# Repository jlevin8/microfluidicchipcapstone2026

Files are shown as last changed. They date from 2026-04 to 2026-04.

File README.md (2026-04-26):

# Microfluidic Chip Capstone 2026

Repository containing CFD files, CAD models, Grayscale slicer scripts, and supplemental materials for honors thesis. 

All CFD was performed using OpenFOAM and Paraview. CAD models were developed using AutoDesk Fusion. Grayscale prints were created using ImageJ scripts. 

Author: Josh Levin
William & Mary

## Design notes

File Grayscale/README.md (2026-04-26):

# bamm_slice README adapted from https://github.com/namitn04/bamm_slice/tree/main

This tool turns a 3D model (`.stl`) into a stack of black-and-white PNG images (layers) that the **CELLINK LumenX Gen-3** printer can use. These instructions are for MacOS users.

## 0) Download this project (no Git needed)

1. On the GitHub page, click the green **Code** button → **Download ZIP**.  
2. Double-click the ZIP to unzip it.  
3. You now have a folder (probably called `microfluidicchipcapstone2026-main`). We’ll use that.

> Tip: Put this folder somewhere easy, like your **Desktop**.

---

## 1) Make sure you have Python 3

1. Open **Terminal**  
   - Press `command + space`, type **Terminal**, hit **Enter**.
2. In Terminal, type:
   ```bash
   python3 --version
   ````

* If you see something like `Python 3.10.9`, you’re good.
* If you get an error, ask someone or ChatGPT to help install Python 3 (it’s quick).

---

## 2) Open Terminal **in** the project folder

Do this the easy way:

1. In **Finder**, open the folder (the one you unzipped).
2. In Terminal, type `cd ` (type `c` + `d` + **space** but don’t press Enter yet).
3. Drag the folder from Finder into the Terminal window (this pastes its full path).
4. Press **Enter**.

Your Terminal line should now end with `…/microfluidicchipcapstone2026-main$`

---

## 3) Install the required packages (one copy-paste line)

In Terminal, paste this and press **Enter**:

```bash
python3 -m pip install trimesh pillow numpy shapely scipy networkx rtree
```

* If that doesn’t work, try:

  ```bash
  pip install trimesh pillow numpy shapely scipy networkx rtree
  ```
* If you see a lot of text — that’s normal. Wait until it finishes.

---

## 4) Run the test (just copy and paste)

Navigate to the `slicer` folder in the `grayscale` in the `microfluidicchipcapstone2026-main` folder:

```bash
cd slicer
```

Then run:

```bash
python3 repair_and_slice.py \
  --stl 3X 20x1mm Cylinders.stl \
  --profile lumenx_gen3.json \
  --layer-mm 0.1 \
  --aa 1 \
  --out ./Test_Output
```

**What this does:**

* Uses the included `.stl` model
* Uses the included `lumenx_gen3.json` printer profile
* Slices the model into **0.1 mm** (100 µm) layers
* Saves PNG images into a new folder called **`Test_Output`**

> The output folder (`./Test_Output`) will be created automatically if it doesn’t exist.

---

## 5) Check that it worked

* In Finder, open the **`Test_Output`** folder that was just created.
* You should see a bunch of files named like `layer_0001.png`, `layer_0002.png`, etc.
* Open a few — the white areas are “exposed” (printed), and black is empty.

---

## 6) Use your own STL next time

When you’re ready to slice a different model:

1. Put your `.stl` file into this same folder (or note where it lives).
2. Run the command again, changing the file names:

**If everything is in the same folder (easy):**

```bash
python3 repair_and_slice.py \
  --stl MyModel.stl \
  --profile lumenx_gen3.json \
  --layer-mm 0.1 \
  --aa 1 \
  --out ./MyModel_Output
```

**If your files are elsewhere (full/absolute paths):**

* On a Mac, you can **drag a file from Finder into Terminal** to paste its full path.

```bash
python3 /Users/yourname/Desktop/microfluidiccapstone2026-main/grayscale/slicer/repair_and_slice.py \
  --stl /Users/yourname/Desktop/Models/MyModel.stl \
  --profile /Users/yourname/Desktop/microfluidicchipcapstone2026-main//grayscale/slicer/lumenx_gen3.json \
  --layer-mm 0.1 \
  --aa 1 \
  --out /Users/yourname/Desktop/MyModel_Output
```

---

## What the options mean (plain English)

* `--stl` — your input 3D model (`.stl` file)
* `--profile` — printer settings; use `lumenx_gen3.json` for LumenX Gen-3
* `--layer-mm` — thickness of each layer. Common values:

  * `0.05` (50 µm, finer, more layers)
  * `0.1` (100 µm, default for quick tests)
* `--aa` — “anti-aliasing” (smooth edges). Leave at `1` unless you know you want `2`.
* `--out` — where to save the PNG layers (a folder you name)

**Quick help at any time:**

```bash
python3 repair_and_slice.py -h
```

---

## Common problems (and quick fixes)

**Q: “command not found: python3”**
A: Python 3 isn’t installed or not in PATH. Install Python 3, then try again.

**Q: “No module named …” or “module not found”**
A: Re-run the install step:

```bash
python3 -m pip install trimesh pillow numpy shapely scipy networkx rtree
```

**Q: “No such file or directory: Test.stl / lumenx_gen3.json”**
A: You’re not in the right folder or not referencing the right file path.

* Either `cd` into the correct folder (see Step 2), **or** use full paths by dragging files into Terminal.

**Q: The output folder is empty / not many layers**
A: Your `--layer-mm` might be too big, or your model is extremely thin. Try `--layer-mm 0.05`.

**Q: The model looks off-center in slices**
A: The script auto-centers each layer for you; if something looks odd, check that your model fits the build area (see below).

---

## Safety fit: does your model fit the printer?

The included LumenX Gen-3 profile uses a build area of **68 mm × 38 mm × 100 mm** and a pixel pitch of **0.035 mm** (35 µm).
If your model is larger than that XY area, scale it down in your CAD before slicing.

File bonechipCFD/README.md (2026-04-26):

# bonechipCFD

OpenFOAM simulation case for serpentine microfluidic channel used in honors thesis.

## Purpose
Steady-state laminar flow simulation to characterize:
- pressure drop
- velocity fields
- streamlines
- wall shear behavior

## Key Directories
- 0/ : initial conditions
- 500/ : final solved state
- constant/ : mesh + material properties
- system/ : solver settings

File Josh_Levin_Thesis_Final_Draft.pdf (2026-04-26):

### A Microfluidic Hydrogel-Based Platform for Modeling Transport-Limited Cellular Environments in Diabetes

A thesis presented in Candidacy for Departmental Honors in

Physics

from

The College of William and Mary in Virginia

By

Josh Levin

4/27/2026

Accepted for ________________________________________

_______________________________________ Dr. Indranath Mitra

_______________________________________ Dr. Margaret Saha

_______________________________________ Jonathan Frey

_______________________________________ Dr. Ran Yang

# Abstract

Diabetic microvascular complications are strongly influenced by the transport of glucose

and signaling molecules across vascular barriers, yet many conventional in vitro disease

models expose cells to static bulk concentrations that do not reproduce physiologically

relevant flow and di!usion behavior. To address this limitation, a modular microfluidic

platform was developed to decouple vascular perfusion from tissue exposure using a per-

fused serpentine channel separated from downstream culture chambers by a tunable hy-

drogel transport barrier. The device was fabricated by combining 3D-printed molds with

PDMS soft lithography, and passive hydrostatic pressure was used to generate continuous

flow through the vascular channel. Computational fluid dynamics simulations were used

to characterize pressure, velocity, and wall shear stress profiles, while grayscale-controlled

photopolymerization was used to fabricate hydrogel barriers with adjustable transport

properties. Experimental characterization demonstrated stable hydrostatic perfusion at

approximately 10 µL/min with laminar flow conditions. Hydrogel thickness after equili-

bration depended on grayscale exposure, with mean final thicknesses of 0.768 mm, 0.656

mm, and 0.511 mm for grayscale values of 255, 200, and 150, respectively. Glucose dif-

fusion studies showed that lower grayscale hydrogels produced greater solute transport,

with normalized relative e!ective di!usivity values of 1.00, 1.23, and 1.70 across the same

conditions. These results demonstrate that grayscale photopolymerization can be used

to tune transport behavior within microfluidic systems and that the developed platform

provides a practical framework for constructing more physiologically realistic vascularized

disease models for diabetes research, drug screening, and future endothelialized organ-on-

chip studies.

i

# Contents

Abstract

Acknowledgements

List of Figures

List of Tables

### 1 Introduction

### 2 Theoretical Background

### 3 Methodology

### 4 Results

ii

### 5 Analysis and Discussion

### 6 Conclusion and Future Work

6.3.3 Role of Transient Concentration Spikes vs Di!usion-Limited Exposure 42 6.3.4 Evaluation of Stem Cell Spheroids in Transport-Controlled Environ-

Appendix A: Computational Modeling Files and Repository

# Acknowledgements

I would like to express my sincere gratitude to Dr. Mitra for his guidance, encourage-

ment, and mentorship throughout the development of this thesis. His insight, patience,

and support were invaluable during each stage of this project. I am especially grateful for

the opportunity to conduct research under his supervision and to learn from his multidis-

ciplinary mindset and approach to scientific inquiry and engineering design. His passion

for his work is contagious, and I cannot wait to see the amazing things he will do at this

institution.

I would also like to thank the members of my thesis committee for their time, feedback,

and willingness to evaluate this work. I cannot overstate the immensely positive impact

each one of them has had on my time here. Their expertise and thoughtful consideration

are greatly appreciated.

I am thankful to the faculty, sta!, and students within the Applied Science and

Physics programs at William & Mary for providing an environment that fostered curiosity,

problem-solving, and interdisciplinary learning. I would also like to acknowledge the labo-

ratory members and peers who o!ered technical assistance, discussion, and encouragement

throughout the course of this project.

Finally, I would like to thank my family and friends for their continued support, pa-

tience, and encouragement throughout my undergraduate career. Their confidence in me

helped make the completion of this thesis possible.

Contribution Statement

This thesis was completed alongside Stone Fisher, who led CFD modeling and aided in

CAD design, chip and hydrogel fabrication, and manuscript preparation. Josh Levin led

conceptual development, CAD design, fabrication, experimental testing, data analysis,

ii

and manuscript preparation under faculty supervision.

1

# List of Figures

3.1 Schematic of the microfluidic bone-on-a-chip platform illustrating separa-

tion of convective flow and di!usive transport | 15

3.2 CAD designs of chip molds. (A) Initial linear perfusion design. (B) Inter-

mediate dual-circle design. (C) Final serpentine design | 16

3.3 CAD design of 3D-printed Franz cell di!usion rig. (A) Front view showing

sampling port and top donor compartment. (B) Side view showing assem-

bly; the hydrogel is placed between the top and bottom compartments and

mechanically clamped between them | 20

4.1 Fabrication workflow for the transport-controlled microfluidic platform. (A)

Computer-aided design renderings of the mold geometries used to create the

serpentine vascular channel and downstream chamber structures. (B) Fab-

ricated molds produced by additive manufacturing. (C) Final transparent

PDMS device components following casting and demolding, shown with a

U.S. penny for size reference | 25

4.2 Hydrostatic perfusion setup used for passive flow generation through the

microfluidic device. Side view of the experimental apparatus showing an el-

evated inlet reservoir connected to the device inlet and a downstream outlet

collection vessel, generating flow through a hydrostatic pressure di!erence

due to 1.0 inch height di!erence | 26

4.3 Simulated pressure distribution along the serpentine vascular channel under

steady-state laminar flow conditions (Pa) | 28

4.4 Streamline visualization of fluid flow within the vascular channel (m/s). . . 28

2

4.5 Velocity magnitude distribution within the vascular channel | 29
4.6 Wall shear stress distribution along the vascular channel | 30

4.7 Mean hydrogel thickness over time during immersion in media for grayscale-

defined constructs (255, 200, and 150), demonstrating condition-dependent

dimensional stabilization | 31

4.8 Mean final hydrated thickness after equilibration. Lower grayscale exposure

produced thinner hydrogel barriers. Error bars represent standard deviation. 31

4.9 Early-time view of receiver glucose accumulation highlighting initial di!er-

ences in transport kinetics between grayscale conditions | 32

4.10 Mean receiver-phase glucose concentration over time following donor expo-

sure. Lower grayscale hydrogels exhibited faster and greater glucose transport. 33

4.11 Normalized transport index proportional to e!ective di!usivity after cor-

rection for final hydrogel thickness. Lower grayscale conditions retained

greater apparent intrinsic transport | 34

3

# List of Tables

4.1 Final Mean Thicknesses of Grayscale Hydrogels | 31
4.2 Mean Receiver Concentrations at 10-hour t=Time Point | 32
4.3 E!ective Di!usivity of Grayscale Hydrogels Normalized to 255 | 33

4

# Chapter 1

# Introduction

Diabetes mellitus is a systemic metabolic disorder characterized by chronic hyperglycemia

and widespread vascular and metabolic dysfunction. While its complications in the car-

diovascular, renal, and nervous systems are well characterized, the e!ects of diabetes on

skeletal health remain incompletely understood (Hofbauer et al. 2022;Napoli et al. 2017).

Clinically, both type 1 and type 2 diabetes are associated with increased fracture risk

and impaired bone healing; paradoxically, individuals with type 2 diabetes often present

with normal or elevated bone mineral density despite heightened fragility (Vestergaard

2007;Schwartz 2016). This discrepancy suggests that diabetes impairs bone quality rather

than bone quantity alone. However, the mechanisms underlying diabetes-associated skele-

tal degeneration remain unresolved.

Bone is a metabolically active and highly vascularized tissue that relies on continuous

nutrient supply to sustain osteoblast, osteoclast, and osteocyte function. Glucose serves

as a primary metabolic substrate for bone cells and plays an essential role in osteoblast

di!erentiation and matrix production (Janghorbani et al. 2007;Karner and Long 2017).

In diabetes, systemic glucose dysregulation leads to persistent hyperglycemia, increased

formation of advanced glycation end products (AGEs), oxidative stress, and endothelial

dysfunction, all of which have been implicated in altered bone remodeling (Yamamoto

and Sugimoto 2016;Jain 1987). Yet it remains unclear whether skeletal dysfunction arises

5

primarily from elevated glucose concentration itself, from altered vascular transport, from

AGE-mediated matrix sti!ening, or from a combination of these factors.

A critical but often overlooked variable in experimental models is the mechanism of

glucose delivery. In vivo, glucose is transported through the vascular network and di!uses

across capillary walls before reaching bone cells. This transport process is governed by vas-

cular flow, endothelial permeability, and di!usion gradients (Michel and Curry 1999;Prisby

2017). In contrast, many in vitro studies model hyperglycemia by directly supplement-

ing cell culture media with high glucose concentrations, e!ectively bypassing the vascular

transport step. While experimentally convenient, this approach assumes that concentra-

tion alone determines cellular response and neglects the role of di!usion-mediated trans-

port dynamics. Whether the mode of glucose delivery influences cellular behavior in

diabetic bone disease remains largely unexplored.

Direct investigation of localized glucose di!usion in vivo is technically challenging

due to bone’s dense mineralized matrix and complex vascular architecture (Prisby 2017).

Animal models provide systemic insight but do not easily allow isolation of microvascular

transport variables, and ethical and cost considerations limit their scalability. Traditional

two-dimensional cell culture models lack a vascular interface altogether and therefore fail to

replicate physiologically relevant nutrient transport. Although bone-on-a-chip platforms

have emerged to model bone physiology and drug responses (Y. Zhang et al. 2023;B.

Zhang et al. 2018), few systems are specifically designed to decouple convective flow from

di!usion through a tunable vascular barrier under diabetic conditions. As a result, a

mechanistically focused platform for studying vascular-mediated glucose di!usion in bone

is needed.

In physiological conditions, glucose transport from blood to tissue occurs via convective

flow within vessels followed by di!usion across the capillary endothelium and basement

membrane. Accurate modeling of this process requires spatial separation of flow and

di!usion through a controllable barrier that approximates capillary permeability. Many

existing microfluidic systems do not incorporate a tunable di!usion barrier that mimics

6

capillary basement membrane properties, limiting their ability to investigate transport-

mediated cellular responses. Addressing this gap is essential for determining whether

di!usion dynamics contribute to skeletal dysfunction in diabetes.

The objective of this work is to design and validate a microfluidic bone-on-a-chip plat-

form capable of modeling glucose di!usion through a hydrogel-based barrier into cell com-

partments under physiologically relevant conditions. By focusing specifically on vascular-

mediated glucose transport rather than full organ complexity, this system aims to isolate

a potentially critical but understudied mechanism in diabetic skeletal pathology.

The proposed device incorporates a tunable hydrogel di!usion barrier positioned be-

tween a perfused vascular channel and cell culture compartments. Glucose-rich media flows

through the vascular channel under laminar conditions, while solute transport into the cell

chambers occurs exclusively via di!usion across the hydrogel barrier. This configuration

separates convective transport from cellular exposure, thereby more closely approximat-

ing in vivo nutrient delivery. The hydrogel barrier is engineered to be tunable to relevant

permeability, enabling controlled investigation of concentration gradients and di!usion

kinetics.

This study employs both experimental and computational approaches. A physical

microfluidic device is fabricated and characterized, while computational fluid dynamics

(CFD) simulations are used to model flow profiles, shear stress, and pressure gradients.

CFD-guided design optimization ensures laminar flow and controlled di!usion prior to fab-

rication. The integration of experimental validation and computational modeling enables

systematic analysis of glucose transport mechanisms within a controllable microenviron-

ment.

While this work is motivated by diabetic skeletal dysfunction, the platform is not lim-

ited to studying disease mechanisms alone. By reconstructing capillary-mediated trans-

port in a controlled microfluidic system, this approach enables evaluation of how biological

systems and potential therapies behave under physiologically realistic delivery conditions.

In particular, therapies that perform well under uniform in vitro exposure may exhibit

7

altered e”cacy when subject to di!usion-limited transport, spatial gradients, and temporal

delays. Capturing these e!ects is essential for improving the predictive accuracy of in vitro

models.

Thus, beyond its mechanistic focus, this system establishes a foundation for transport-

informed drug testing and personalized disease modeling, where both biological response

and delivery dynamics can be systematically controlled and evaluated.

8

# Chapter 2

# Theoretical Background

## 2.1 Literature Review

### 2.1.1 Organ-on-a-Chip (OOC) Technology

Current drug discovery and toxicological research are limited by a lack of reliable pre-

dictive models that can accurately assess human physiological responses(Van Norman

2019). Animal models remain a primary source for pharmacokinetic data because they

capture complex in vivo physiology, but they often fail to predict human outcomes due to

species-specific metabolic and physiological di!erences, in addition to raising significant

ethical concerns(Seok, Warren, Cuenca, et al. 2013). Conversely, traditional 2D in vitro

models are simple and low-cost but fail to replicate the dynamic 3D cellular microenvi-

ronment, resulting in cells that lack the morphology, polarity, and behavior observed in

vivo(Edmondson et al. 2014).

Organ-on-a-Chip (OOC) technology has emerged as a bridge between these methods,

combining micro-engineering with 3D cell culture to recapitulate organ-level functions. By

utilizing human cells in dynamic microfluidic environments, these devices provide the me-

chanical and chemical cues (such as fluid flow and shear stress) necessary for more accurate

personalized disease modeling and drug screening. Bone-on-a-chip platforms specifically

allow for the investigation of bone adaptation, repair, and diseases like osteoporosis within

9

a controlled, biomimetic system.

### 2.1.2 The Basement Membrane and Capillary Interface

The basement membrane (BM) is a specialized extracellular matrix structure that un-

derlies endothelial and epithelial tissues, forming a selective barrier between the vascular

lumen and surrounding parenchyma (Yurchenco 2011). Ultrastructurally, it consists of

the lamina lucida, lamina densa, and lamina fibroreticularis. The lamina densa, primarily

composed of type IV collagen and laminins, provides mechanical support and contributes

significantly to molecular filtration properties (Yurchenco 2011).

In bone, nutrient exchange occurs through a highly vascularized network that in-

cludes sinusoidal capillaries within the marrow space (Williamson, Kilo, and Tilton 1993).

Capillary-mediated transport involves convective flow within vessels followed by di!usion

across the endothelial layer and basement membrane before solutes reach interstitial tissue.

Transport is governed by permeability, surface area, and concentration gradients (Bird,

Stewart, and Lightfoot 2002).

In diabetic conditions, microvascular dysfunction and basement membrane thickening

have been documented across multiple tissues (Brownlee 2001). These structural alter-

ations may influence solute flux into tissues; however, most in vitro diabetic bone models

bypass the vascular interface entirely by directly exposing cells to hyperglycemic media.

Consequently, the influence of capillary-mediated di!usion dynamics on skeletal cell be-

havior remains poorly characterized

### 2.1.3 Hydrogels as Biomimetic Sca!olds

Hydrogels are three-dimensional crosslinked polymer networks capable of retaining large

volumes of water, making them structurally and mechanically similar to native ECM

(Peppas et al. 2000). Their high water content supports di!usion of small solutes, while

their mesh size and crosslinking density regulate permeability and mechanical sti!ness.

Photocrosslinkable materials such as polyethylene glycol diacrylate (PEGDA) and

10

gelatin methacryloyl (GelMA) are widely used in microfluidic and tissue-engineered sys-

tems due to their tunable mechanical properties, cytocompatibility, and optical trans-

parency (Zhu and Marchant 2011;Yue et al. 2015). PEG-based hydrogels provide con-

trolled di!usivity with minimal protein adsorption, whereas GelMA incorporates bioactive

motifs that promote cell adhesion.

In this work, a hydrogel layer functions as an artificial basement membrane positioned

between a perfused vascular channel and cell compartments. By tuning polymer concen-

tration and crosslinking density, the hydrogel permeability can be adjusted to approximate

physiological capillary transport while maintaining mechanical stability. Unlike rigid mem-

branes, hydrogel barriers more closely resemble the compliant and hydrated structure of

native capillary interfaces.

## 2.2 Governing Physics

### 2.2.1 Mass Transport and Di!usion Kinetics

Solute transport across the hydrogel barrier is governed primarily by passive di!usion. For

time-dependent systems, concentration profiles are described by Fick’s Second Law:

ωC
ωt = D→²C

where C is solute concentration, D is the e!ective di!usion coe”cient within the hy-

drogel, and t represents time.

Within polymeric networks, e!ective di!usion coe”cients are reduced relative to free

solution and depend on mesh size, tortuosity, and solute–polymer interactions (Bird, Stew-

art, and Lightfoot 2002). Small molecules such as glucose (↑ 180Da) typically experience

modest hindrance, whereas larger macromolecules may exhibit restricted transport.

Transport selectivity in hydrogels arises through two primary factors: size exclusion

determined by the relationship between solute hydrodynamic radius and mesh size, and

interaction-based filtering, including electrostatic and hydrophobic interactions that alter

e!ective di!usivity independent of size (Bird, Stewart, and Lightfoot 2002;Amsden 1998).

11

When modeling small di!usion cells, lateral di!usion at the membrane edges (“edge

e!ects”) can artificially elevate apparent steady-state flux if not properly constrained,

particularly when the e!ective di!usion area exceeds the exposed cross-sectional region

(Bird, Stewart, and Lightfoot 2002). Device geometry must therefore be incorporated into

computational modeling.

### 2.2.2 Computational Fluid Dynamics and Laminar Flow

Microfluidic systems typically operate at low Reynolds numbers (Re <1–100), where vis-

cous forces dominate inertial forces and flow remains laminar (Whitesides 2006). Under

laminar conditions, velocity profiles are predictable and mixing occurs primarily by di!u-

sion rather than turbulence.

CFD simulations are employed to validate laminar flow conditions within the vascular

channel, predict wall shear stress experienced by endothelial cells, model velocity and

pressure gradients, and optimize channel geometry to ensure uniform concentration along

the barrier.

For perfused systems with su”ciently high flow rates relative to di!usion flux, the

donor channel may be approximated as an infinite source, maintaining a near-constant

concentration at the hydrogel boundary (infinite dose assumption).

### 2.2.3 Glucose Transport and Utilization Modeling

Glucose transport within biological systems involves both passive di!usion through ex-

tracellular environments and active cellular uptake. In many cell types, glucose uptake

is mediated by facilitative transporters such as GLUT proteins and can be described us-

ing Michaelis–Menten kinetics, where uptake rate depends on local glucose concentration.

Glucose uptake in bone cells is mediated primarily by facilitative glucose transporters such

as GLUT1 and, under certain conditions, GLUT4 (Brownlee 2001;Williamson, Kilo, and

Tilton 1993).

In systems where transport and consumption are coupled, spatial concentration profiles

12

may be influenced not only by di!usion but also by cellular metabolic demand, potentially

leading to localized depletion gradients. Modeling such behavior typically requires cou-

pling di!usion equations with reaction terms representing cellular uptake.

In the present work, transport analysis focuses on di!usion-driven delivery across the

hydrogel barrier, and cellular consumption is not explicitly modeled. This simplification

allows isolation of transport dynamics as a primary variable. However, incorporation

of coupled di!usion–consumption models represents an important extension for future

studies, particularly in the context of evaluating metabolically active systems such as

stem cell spheroids.

## 2.3 Theoretical Assumptions

To enable tractable analysis and computational modeling, several simplifying assumptions

are applied to the system. These assumptions are selected to preserve the dominant

physical behavior while allowing analytical and numerical treatment of transport processes.

The hydrogel barrier is not assumed to be globally homogeneous. In the present

design, spatial variations in crosslinking density may be introduced through grayscale-

controlled photopolymerization to approximate structural heterogeneity observed in native

basement membranes. However, for modeling purposes, the hydrogel is treated as locally

homogeneous, such that within su”ciently small regions the e!ective di!usion coe”cient

may be considered constant. This allows application of Fickian di!usion within each local

domain while permitting spatial variation in transport properties at larger scales.

The e!ective di!usion coe”cient D is therefore treated as a spatially varying parameter,

D=D(x,y,z), reflecting heterogeneity in mesh size and crosslinking density. In simplified

models or initial approximations, an average or e!ective di!usion coe”cient may be used

to represent bulk transport behavior.

Solute transport across the hydrogel is assumed to occur primarily through passive

di!usion, with negligible convective flow within the gel matrix. This assumption is justified

by the low permeability and small pore size of the hydrogel, which suppresses bulk fluid

13

motion.

At the interface between the vascular channel and the hydrogel, solute concentration

is assumed to be continuous, with no preferential partitioning or interfacial resistance.

Additionally, due to continuous perfusion of the vascular channel, concentration at the

hydrogel boundary is approximated as constant over time, consistent with an infinite

source condition.

The hydrogel–cell chamber interface is assumed to allow unrestricted di!usion into

the receptor compartment, without additional transport barriers. Cellular uptake and

consumption of solutes are not included in the present transport model, allowing isolation

of di!usion-driven behavior.

Finally, the system is assumed to operate under steady-state or quasi-steady-state

conditions for flow, with transient e!ects considered only in di!usion analysis. These

assumptions collectively enable focused investigation of transport dynamics while main-

taining relevance to the physical behavior of the system.

14

# Chapter 3

# Methodology

## 3.1 System Overview

The development of the bone-on-a-chip microfluidic platform follows an iterative engineer-

ing design framework consisting of three sequential phases: (1) fabrication optimization,

(2) transport and fluidic validation, and (3) biological characterization. The system is

engineered to isolate and model capillary-mediated passive di!usion of soluble factors into

a compartmentalized tissue microenvironment. While diabetic conditions serve as a pri-

mary application, the platform is designed more broadly as a transport-controlled testbed

for evaluating biological response under physiologically relevant delivery constraints.

As shown in Figure 3.1, the device consists of a serpentine vascular channel (top

layer) connected to inlet and outlet ports, positioned above multiple cell culture chambers

(bottom layer). A hydrogel di!usion barrier is embedded at the interface between the

channel and each chamber, permitting passive transport of soluble factors while preventing

direct convective flow into the cellular compartment. This architecture enables controlled

delivery of nutrients and signaling molecules, allowing cells to experience spatially and

temporally varying concentrations that more closely mimic in vivo capillary-mediated

transport.

Unlike conventional static 2D cultures, this system spatially separates convective flow

from cellular compartments using a hydrogel-based di!usion barrier. By incorporating con-

15

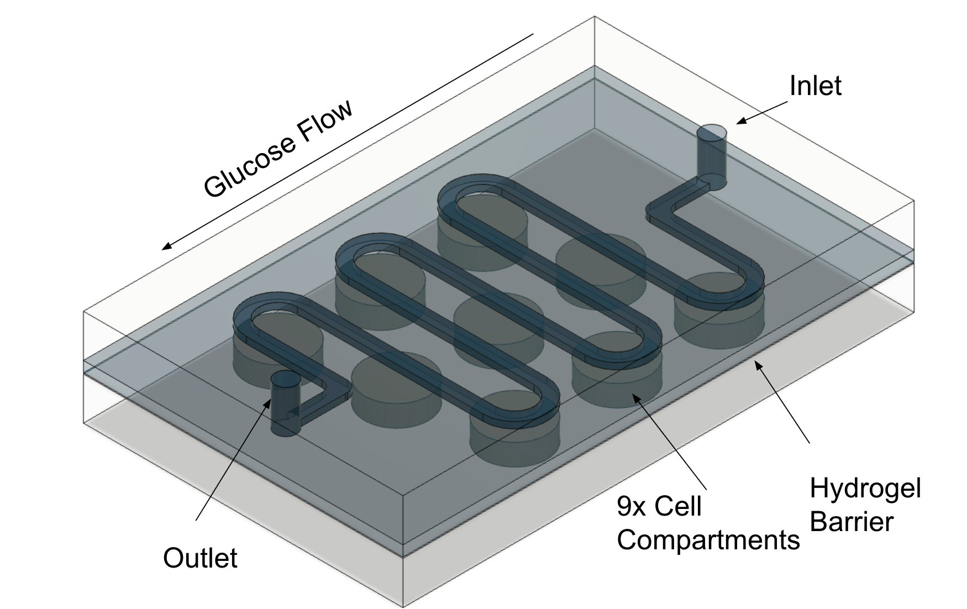
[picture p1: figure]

Figure 3.1: Schematic of the microfluidic bone-on-a-chip platform illustrating separation of convective flow and di!usive transport.

trolled laminar perfusion and tunable solute permeability, the platform enables mechanis-

tic interrogation of vascular-mediated transport under diabetic conditions. This approach

bridges the gap between reductionist in vitro systems and complex in vivo physiology

while maintaining experimental controllability.

## 3.2 Device Design and Fabrication

### 3.2.1 CAD and Microfluidic Architecture

The final microfluidic platform developed in this study was preceded by several itera-

tive design stages aimed at balancing physiological relevance, manufacturability, residence

time, and experimental throughput. Because the primary objective of the system was to

model vascular transport to downstream tissue chambers, the geometry of the perfused

channel required progressive refinement to improve exposure dynamics while maintain-

ing straightforward fabrication through soft lithography. The major design stages are

summarized in Figure 3.2.

The first design iteration employed a simple linear perfusion channel positioned above

two downstream cell compartments (Figure 3.2-A). In this concept, fluid entered through a

single inlet, traveled through a straight vascular channel, and exited through a downstream

outlet. Two circular culture chambers were aligned beneath the channel to receive di!usive

transport through the hydrogel barrier separating the vascular and tissue regions.

16

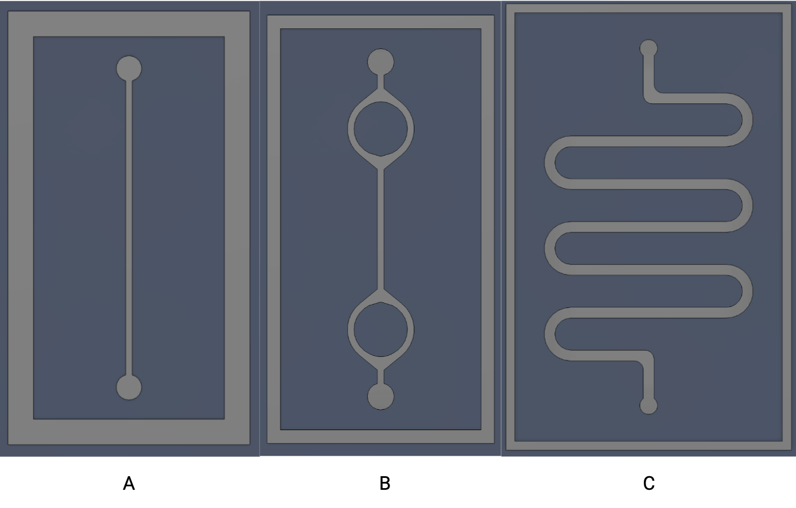
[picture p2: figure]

Figure 3.2: CAD designs of chip molds. (A) Initial linear perfusion design. (B) Intermediate dual-circle design. (C) Final serpentine design.

This design was selected as an initial prototype because of its simplicity and low

fabrication risk. Straight channels are easy to model computationally, easy to mold using

additive manufacturing, and less susceptible to flow irregularities or trapped air bubbles

during early testing. Additionally, the minimal geometry allowed rapid evaluation of

bonding methods, leakage behavior, hydrogel placement, and general perfusion feasibility

before committing to more complex layouts.

However, the straight-channel design exhibited several conceptual limitations. Most

notably, the short flow path produced limited fluid residence time above the downstream

compartments, reducing the duration of local nutrient and solute exposure. The design

also poorly represented the tortuous nature of physiological microvasculature and o!ered

only two tissue compartments, restricting throughput and comparative studies. Because

exposure conditions were likely dominated by rapid axial transport rather than prolonged

exchange, a more developed geometry was pursued.

To increase path length while preserving a compact footprint, a second design iteration

was developed in which the vascular channel looped around two circular regions before

continuing downstream (Figure 3.2-B). In this architecture, the channel traced circular

paths around each compartment, increasing total channel length relative to the straight

design while maintaining two primary culture sites.

The rationale for this geometry was to enhance fluid residence time and create longer

vascular contact regions surrounding each chamber. By increasing the time perfusate

17

spent adjacent to the tissue compartments, the design was expected to improve di!usive

transport opportunities across the hydrogel barrier.

Despite these advantages, several limitations remained. The system still contained

only two culture chambers, limiting experimental throughput. Channel length increased

only modestly relative to later designs, and the circular loops did not fully utilize the

available chip footprint. Additionally, the compartment arrangement was less modular

and did not provide multiple spatial positions for comparing upstream versus downstream

exposure e!ects. As a result, a higher-density architecture was pursued.

The final design iteration employed a serpentine vascular channel spanning the full

device footprint, coupled with an expanded downstream chamber array (Figure 3.2-C).

This geometry substantially increased channel length while maintaining a compact pla-

nar footprint and introduced repeated turns resembling the tortuous routing commonly

observed in vascular networks.

The serpentine channel was selected for several reasons. First, the extended flow path

increased hydraulic residence time, allowing solutes more time to di!use across the hy-

drogel barrier before outlet removal. Second, the repeated curvature generated localized

variations in velocity and wall shear stress that more closely resemble nonuniform physio-

logical flow conditions than a straight channel. Third, the design used chip area e”ciently,

enabling integration of multiple tissue compartments without increasing device size.

The chamber array was expanded from earlier two-chamber designs to a total of nine

compartments to improve throughput and enable spatial comparisons. Six chambers were

positioned adjacent to curved serpentine segments, while three were located near relatively

straight sections of channel. This arrangement was intentionally selected to investigate

whether local residence time or geometric flow di!erences influenced downstream transport

behavior. Curved segments were expected to exhibit slightly longer local interaction times

and altered flow distributions compared with straightaways, potentially a!ecting solute

delivery to neighboring chambers.

Although the serpentine design introduced greater fabrication complexity than the

18

earlier linear geometries, the increased channel length, higher compartment density, and

improved physiological resemblance justified the transition. The final architecture pro-

vided the most versatile platform for studying transport-controlled cellular exposure while

retaining compatibility with PDMS molding and hydrostatic pressure-driven perfusion.

Overall, the CAD development process demonstrates that the final chip geometry was

not selected arbitrarily, but emerged through iterative engineering refinement in response

to the competing requirements of transport performance, manufacturability, and experi-

mental utility.

The microfluidic device is designed using Computer-Aided Design (CAD) software

(Autodesk Fusion 360), incorporating established organ-on-a-chip architectural principles

(Waheed et al. 2016). The platform consists of a sandwich design, with a serpentine per-

fused vascular channel (donor compartment) making up the top PDMS slab, a hydrogel

barrier in the middle, and nine independent cell culture chambers (receptor compart-

ments), arranged symmetrically with three chambers per side and three in the middle.

The vascular channel connects inlet and outlet ports to enable continuous perfusion of

glucose-containing media under controlled flow rates. Each cell chamber interfaces with the

vascular channel via a dedicated aperture engineered to house a hydrogel di!usion barrier.

This barrier prevents convective mixing while permitting passive solute transport.

Channel geometry is designed to maintain laminar flow (Re <100) and uniform solute

concentration along the hydrogel interface. The cylindrical layout reduces concentration

gradients between the upstream and downstream compartments.

3.2.2 3D Printing and Material Selection

Device fabrication is performed using Digital Light Processing (DLP) 3D printing due to

its high resolution (10–30 µm), rapid prototyping capability, and reproducibility (Waheed

et al. 2016)(Huh et al. 2010). Candidate materials include biocompatible photocurable

resins and PDMS validated for microfluidic applications (Waheed et al. 2016).

Molding with Sylgard 184 PDMS (10:1 base:curing agent ratio) is used for fabrication.

19

PDMS remains widely used in microfluidics due to optical transparency, gas permeability,

and ease of plasma bonding (Bhatia and Ingber 2014). Dimensional fidelity and channel

integrity are verified by microcaliper measurement.

### 3.2.3 Hydrogel Barrier Fabrication and Integration

A semi-permeable hydrogel membrane functions as a biomimetic surrogate of the capil-

lary basement membrane. Photocrosslinkable hydrogels such as PEGDA and GelMA are

selected due to their tunable crosslink density, biocompatibility, and well-characterized

di!usion properties.

Hydrogel precursor solution containing photoinitiator (LAP) is introduced into the

DLP print vat. Controlled UV or visible-light exposure induces crosslinking, forming a

stable membrane that is then placed between the PDMS slabs.

Hydrogel thickness, polymer concentration, and crosslinking time are systematically

varied to modulate e!ective di!usion coe”cients. Membrane formation is validated visu-

ally and through leakage testing prior to transport experiments.

## 3.3 Transport Validation and Data Acquisition

### 3.3.1 Computational Fluid Dynamics (CFD)

CFD simulations are conducted using OpenFOAM CFD to evaluate hydrodynamic be-

havior and solute transport. The Navier–Stokes equations are solved under steady-state

laminar flow conditions (Amsden 1998).

Medium properties are modeled as water at 37°C, with dynamic viscosity (µ) = 7.75

× 10 kg/(m·s) and density (ω) = 1000 kg/m³. Simulations are performed to confirm

Reynolds number within laminar regime, quantify wall shear stress on endothelial surfaces

and evaluate velocity uniformity along the hydrogel interface.

20

### 3.3.2 Di!usion and Permeability Assays

Quantitative characterization of hydrogel transport behavior required the development

of a practical di!usion testing method compatible with the mechanically soft grayscale-

printed hydrogel samples used in this study. Because these hydrogels were intended to

function as transport barriers within the microfluidic platform, an experimental system

was needed that could isolate the material between donor and receiver compartments while

maintaining structural integrity during multi-hour testing.

Initial Franz Cell–Inspired Di!usion Chamber Design

The initial approach employed custom 3D-printed di!usion cells (see Figure 3.3) inspired

by traditional Franz di!usion chambers. These devices were fabricated from polyethylene

terephthalate glycol (PETG) and consisted of donor and receiver reservoirs designed to

sandwich the hydrogel sample between two rigid printed halves. Mechanical compression

was applied using binder clips to seal the assembly and prevent leakage.

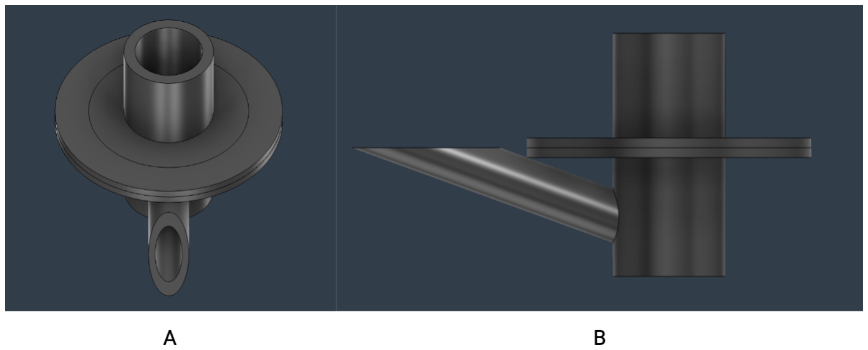
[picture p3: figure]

Figure 3.3: CAD design of 3D-printed Franz cell di!usion rig. (A) Front view showing sampling port and top donor compartment. (B) Side view showing assembly; the hydrogel is placed between the top and bottom compartments and mechanically clamped between them.

This method o!ered several theoretical advantages. First, it provided clear physi-

cal separation between donor and receiver chambers, enabling one-dimensional transport

through the hydrogel barrier. Second, the clamped design was low-cost, reusable, and

rapidly fabricated using standard additive manufacturing methods. Third, the chamber

geometry allowed straightforward filling and sampling of both compartments.

However, repeated testing revealed a critical limitation: the grayscale-defined hydrogels

21

lacked su”cient mechanical robustness to withstand sustained compressive loading at the

sealing interface. Even moderate binder clip pressure frequently caused tearing, cracking,

edge deformation, or rupture of the hydrated gels during assembly. Because seal integrity

depended directly on compression force, reducing clamp pressure often led to leakage, while

increasing pressure damaged the hydrogel. This tradeo! made the Franz cell approach

unreliable for fragile hydrogel formulations.

Following these failures, several additional mechanically clamped testing concepts were

considered, including using syringes as donor and receptor chambers. While these designs

could potentially lower local stress concentrations, they retained the same fundamental

challenge: accurate di!usion measurements required leak-free compartment separation,

while the hydrogels could not reliably tolerate compressive sealing loads. Given project

time constraints and limited material availability, continued iteration on compression-

based fixtures was deprioritized.

Final Six-Well Plate Drop Di!usion Method

A simplified static di!usion assay was therefore adopted using standard six-well culture

plates. In this final configuration, individual hydrogels were placed in wells containing a

defined volume of media as the receiver. A concentrated donor droplet containing glucose

solution was then deposited directly on the upper hydrogel surface.

In this arrangement, glucose transport occurred from the donor droplet through the

hydrogel thickness into the surrounding receiver media below. Receiver-phase glucose con-

centration was measured at scheduled time points using a glucometer to compare relative

transport behavior across grayscale conditions.

The six-well plate method was selected because it eliminated the need for mechanical

compression, substantially reducing hydrogel damage and sample loss. It also enabled

parallel testing of multiple conditions and replicates using widely available laboratory ma-

terials. Sample loading, retrieval, and handling were significantly faster than with custom

clamped fixtures, improving experimental throughput during late-stage thesis testing.

22

The final method was intentionally selected as a comparative transport assay rather

than a perfect classical di!usion cell analog. Its major benefits included no compres-

sive stress on fragile hydrogels, rapid parallel testing of multiple grayscale conditions,

minimal custom hardware requirements, and reduced leakage risk relative to clamped fix-

tures. However, its limitations included less strictly defined one-dimensional transport

geometry, possible donor droplet spreading variability, potential evaporative e!ects dur-

ing long-duration tests, and greater sensitivity to hydrogel placement consistency. This

made it more appropriate for relative di!usivity comparisons than absolute permeability

extraction.

Despite these limitations, the method was su”cient to resolve reproducible grayscale-

dependent transport trends and therefore served to determine whether grayscale-controlled

photopolymerization could be used to tune hydrogel barrier transport properties.

For each condition, equilibrated hydrogels were transferred into six-well plates con-

taining receiver media of known volume. A glucose donor droplet of fixed volume and

concentration was applied to the hydrogel surface using the pipette guide fixture. Re-

ceiver media glucose concentration was then measured at predetermined intervals over 48

hours. Triplicate samples were tested for each grayscale condition (255, 200, and 150),

and resulting concentration profiles were used to estimate relative e!ective di!usivity after

correction for measured hydrogel thickness.

### 3.3.3 Hydrostatic Pressure-Driven Flow

Continuous flow within the microfluidic device is achieved using a hydrostatic pressure-

driven setup. Fluid reservoirs connected to the inlet and outlet ports are positioned at

di!erent vertical heights to establish a gravitational pressure gradient across the device.

The inlet reservoir consists of a vertically mounted syringe or fluid column containing

glucose- or solute-enriched media. The outlet tubing is directed to a waste reservoir

positioned at a lower elevation. The resulting height di!erence between the fluid levels

generates a pressure di!erential that drives flow through the vascular channel.

23

To ensure reproducibility across experiments, all devices are operated under identical

height di!erences, and tubing lengths and diameters are kept consistent to maintain uni-

form hydraulic resistance. Prior to each experiment, all channels and tubing are primed

with media to eliminate air bubbles, which can disrupt flow stability.

Flow rates are estimated by collecting e#uent over a fixed time interval and calculating

the volumetric flow rate. These measurements are used to verify that experimental flow

conditions fall within the laminar regime predicted by CFD simulations.

To minimize temporal variation in flow rate due to depletion of the inlet reservoir,

relatively large fluid volumes are used such that the change in hydrostatic head over the

course of the experiment remains small. This approach enables sustained, low-Reynolds-

number perfusion suitable for long-duration transport and cell culture studies.

24

# Chapter 4

# Results

## 4.1 Device Fabrication and Dimensional Validation

The microfluidic platform was successfully fabricated using a mold-based soft lithography

workflow designed to produce a vascular serpentine channel adjacent to a larger down-

stream cell chamber separated by a hydrogel interface region. The device geometry was

first designed in CAD software and exported as a stereolithography (STL) model for

additive manufacturing of the mold. Following mold fabrication, polydimethylsiloxane

(PDMS) was cast, cured, and removed from the mold to generate the final microfluidic

layer. Inlet and outlet ports were created with syringe tips to permit fluidic connection to

external reservoirs, and the device was subsequently bonded to a flat substrate to complete

the enclosed channel architecture. Representative images of the design, printed mold, and

cured PDMS chips are shown in Figure 4.1.

Measured device dimensions were compared to the nominal geometry defined in the

CAD model to assess fabrication accuracy. The microchannel had sub-millimeter dimen-

sions, with an average height of 0.468 ± 0.022 mm and width of 0.881 ± 0.105 mm, consis-

tent with the design intent. The total channel length was measured to be approximately

21.01 mm, aligning with the expected serpentine geometry used to increase residence time.

The cell compartment dimensions (3.038 ± 0.030 mm width and 1.354 ± 0.008 mm height)

were also consistent across samples and matched the intended expansion of the di!usion

25

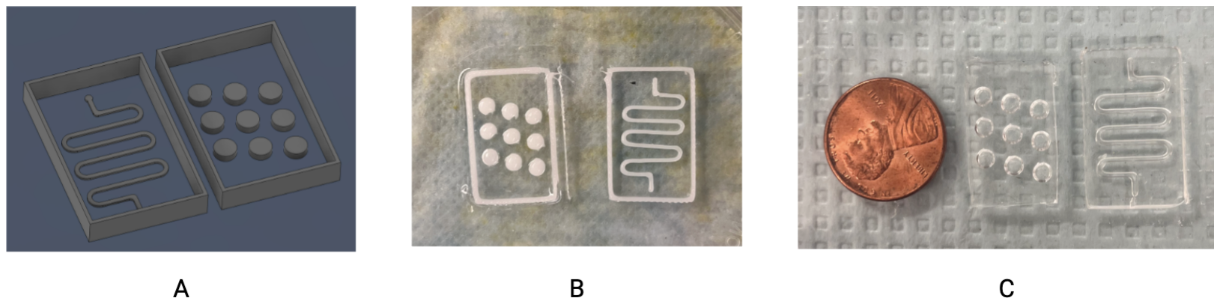
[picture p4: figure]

Figure 4.1: Fabrication workflow for the transport-controlled microfluidic platform. (A) Computer-aided design renderings of the mold geometries used to create the serpentine vascular channel and downstream chamber structures. (B) Fabricated molds produced by additive manufacturing. (C) Final transparent PDMS device components following casting and demolding, shown with a U.S. penny for size reference.

region relative to the microchannel. Minor deviations from the nominal design are at-

tributed to fabrication limitations and measurement uncertainty at small scales, but these

di!erences are not expected to impact flow or transport behavior significantly. Overall,

the fabricated device dimensions demonstrate acceptable agreement with the design speci-

fications and support the validity of subsequent experimental and computational analyses.

## 4.2 Flow Characterization and Validation of the Vascular

## Channel

Hydrodynamic performance of the vascular channel was evaluated to determine whether

the fabricated device could sustain stable perfusion under physiologically relevant mi-

crofluidic conditions. Flow through the serpentine channel was driven passively using a

hydrostatic pressure gradient established by a height di!erence between inlet and outlet

reservoirs (See Figure 4.2). This approach eliminated the need for external pumps while

enabling steady low-flow operation over extended time periods.

The measured average flow rate under standard operating conditions was approxi-

mately 10 µL/min based on outlet volume collection. Given the measured channel cross-

sectional dimensions (0.881 mm width × 0.468 mm height), this corresponds to an average

linear velocity of approximately 0.40 mm/s within the channel. This velocity lies within

26

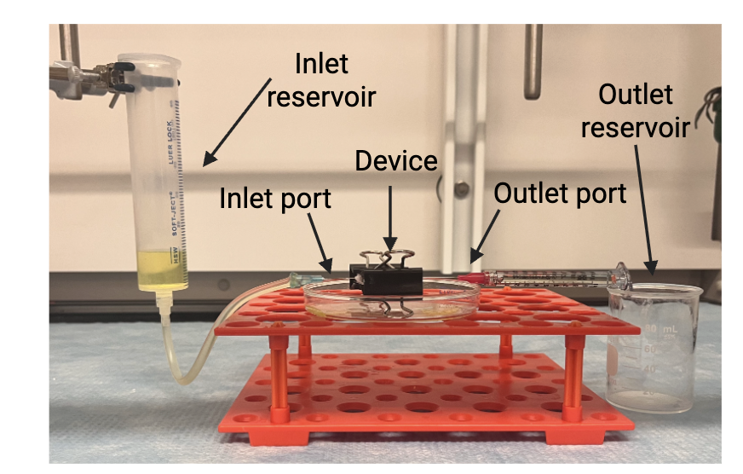
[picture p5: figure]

Figure 4.2: Hydrostatic perfusion setup used for passive flow generation through the microfluidic device. Side view of the experimental apparatus showing an elevated inlet reservoir connected to the device inlet and a downstream outlet collection vessel, generating flow through a hydrostatic pressure di!erence due to 1.0 inch height di!erence.

the lower range reported for physiological capillary microcirculation, where resting capil-

lary blood velocities on the order of 0.3–1.8 mm/s have been observed, and is therefore

consistent with low-shear microvascular transport environments (Hudetz 1997). As a re-

sult, the selected operating condition was considered suitable for mimicking transport

conditions relevant to nutrient delivery in vivo.

The Reynolds number was estimated using measured geometry and water-like fluid

properties:

Re = εUD
µ

where U is the mean velocity, and D is the hydraulic diameter of the rectangular

channel. Under the measured flow condition, the Reynolds number remained well below

unity, confirming strongly laminar flow dominated by viscous forces. This behavior is

27

expected in microfluidic systems and is advantageous because it produces predictable

transport conditions without turbulence or flow instabilities.

Computational fluid dynamics simulations further supported the experimental obser-

vations. Velocity contours demonstrated a relatively uniform axial flow profile through the

straight channel segments, with localized increases in velocity near channel bends due to

curvature-induced redistribution of streamlines. Pressure decreased monotonically along

the length of the serpentine path, indicating consistent hydraulic resistance throughout

the device. Streamline plots showed smooth trajectories without recirculation zones or

stagnation regions.

The serpentine geometry increased the e!ective channel length to approximately 80

mm while maintaining a compact device footprint. This extended path length provided two

functional advantages: increased hydraulic resistance, allowing physiologically relevant low

flow rates to be achieved using modest hydrostatic pressure, and increased residence time,

permitting prolonged interaction between the flowing media and the hydrogel transport

interface.

At the measured average velocity of 0.40 mm/s, the estimated fluid residence time

through the vascular channel was approximately:

t = L

U = 80mm
0.40mm/s ↑ 200s.

or roughly 3.3 minutes. This residence time is su”cient to support sustained solute

exchange along the hydrogel interface during perfusion.

Overall, both experimental measurements and computational modeling indicate that

the device successfully supports stable, low-Reynolds-number perfusion in a physiologi-

cally relevant flow regime. These results validate the serpentine vascular channel as an

appropriate upstream transport module for subsequent di!usion-controlled studies.

Pressure distribution along the serpentine channel confirms a stable pressure-driven

flow regime. As shown in Figure 4.3, pressure decreases monotonically from inlet to

outlet, with no abrupt discontinuities or localized regions of stagnation. This smooth

gradient indicates that flow is governed by viscous forces and that the system operates

28

under steady-state conditions. The absence of pressure irregularities ensures a consistent

driving force for fluid motion, which is critical for maintaining uniform solute delivery

along the hydrogel interface.

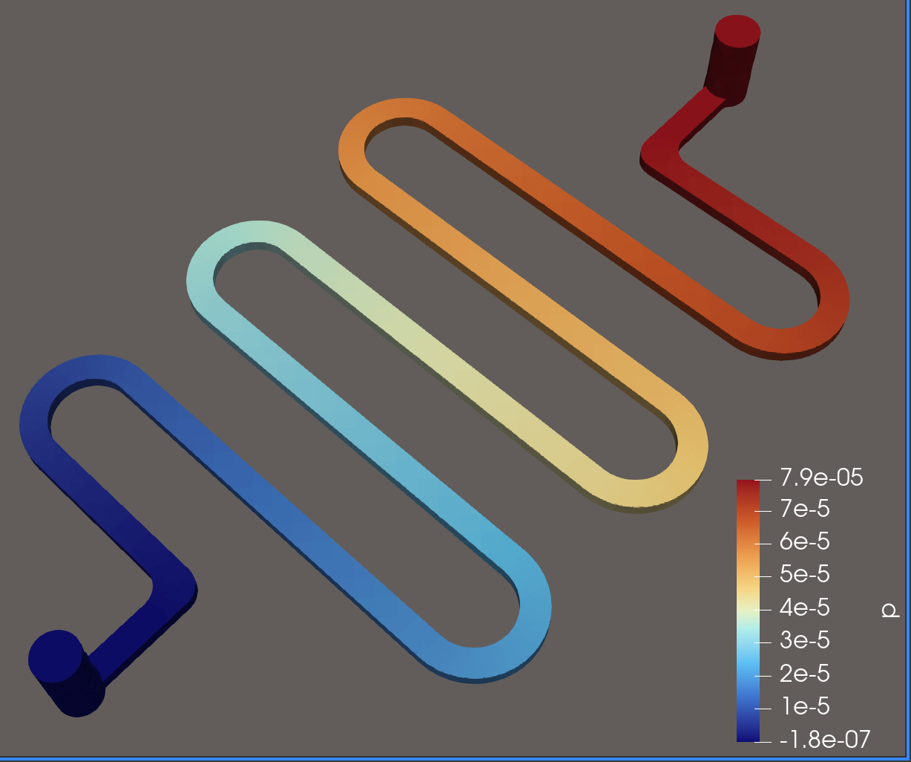
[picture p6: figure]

Figure 4.3: Simulated pressure distribution along the serpentine vascular channel under steady-state laminar flow conditions (Pa).

Flow structure within the channel further supports laminar behavior. Streamline vi-

sualization (Figure 4.4) demonstrates smooth, continuous flow paths that closely follow

the channel geometry, including through curved segments. No recirculation zones or vor-

tices are observed, indicating that inertial e!ects are negligible and that mixing within the

channel occurs primarily through di!usion rather than turbulence. This is consistent with

the low Reynolds number regime typical of microfluidic systems and ensures predictable

transport of solutes to the di!usion barrier.

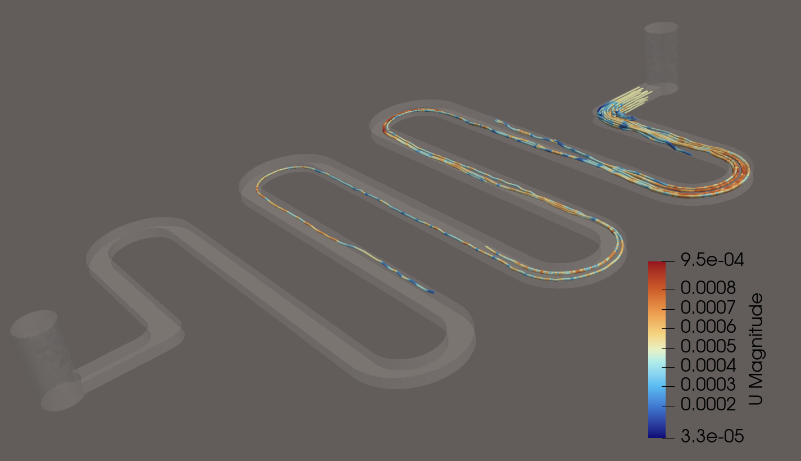
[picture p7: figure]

Figure 4.4: Streamline visualization of fluid flow within the vascular channel (m/s).

29

Velocity field analysis provides additional confirmation of stable flow conditions. As

shown in Figure 4.5, velocity profiles exhibit characteristic laminar behavior, with maxi-

mum velocities at the channel center and reduced velocities near the walls due to viscous

drag. Importantly, velocity remains relatively uniform along the length of the channel,

despite the serpentine geometry. This spatial consistency supports the assumption of a

near-constant solute concentration at the hydrogel boundary, justifying treatment of the

vascular channel as an e!ectively well-mixed donor compartment in subsequent transport

analysis.

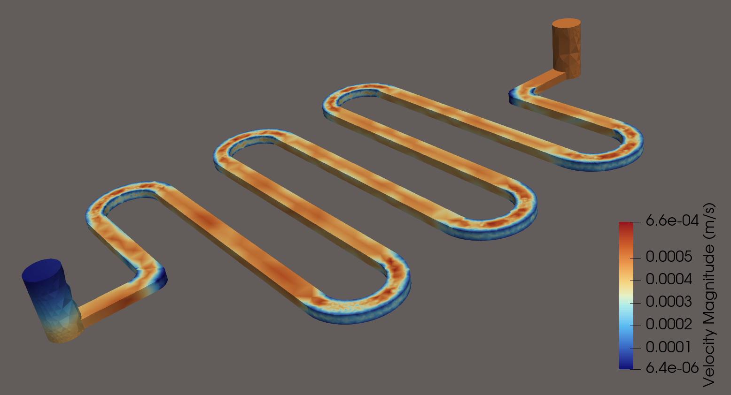
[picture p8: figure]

Figure 4.5: Velocity magnitude distribution within the vascular channel.

Wall shear stress was evaluated to characterize mechanical conditions at the channel

interface. As shown in Figure 4.6, shear stress is elevated at channel bends, where direc-

tional changes in flow induce higher velocity gradients, and reduced in straight sections.

Overall shear levels remain low and within ranges typical of microfluidic perfusion systems.

While endothelial cells are not incorporated in the current study, these values suggest that

the system is compatible with future integration of vascular cell layers without inducing

excessive mechanical stress.

Taken together, these results demonstrate that the vascular channel provides stable,

laminar, and spatially consistent flow conditions suitable for controlled solute delivery. The

absence of recirculation, uniform velocity distribution, and predictable pressure gradient

support the use of this system as a well-defined upstream boundary for di!usion-driven

transport across the hydrogel barrier.

30

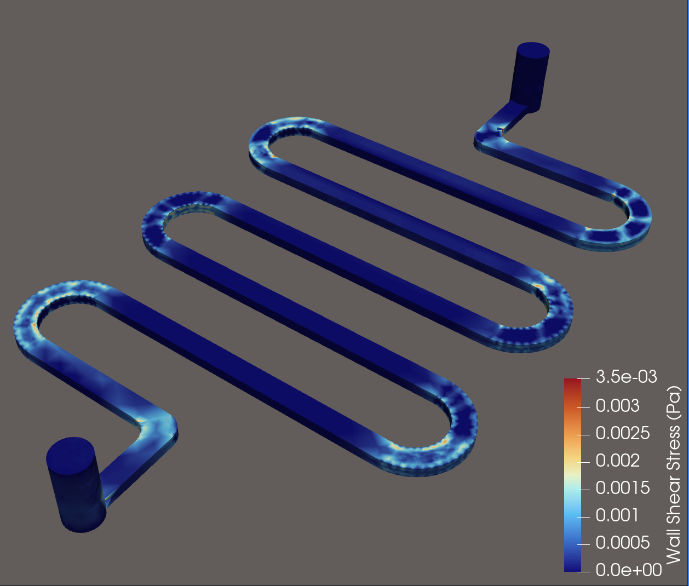
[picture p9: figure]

Figure 4.6: Wall shear stress distribution along the vascular channel.

## 4.3 Hydrogel Characterization and Di!usion Tuning

The hydrogel interface serves as the central transport-regulating component of the mi-

crofluidic platform. In the present system, grayscale-controlled photopolymerization was

used to generate hydrogels with di!ering e!ective crosslink densities, allowing transport

behavior to be tuned through fabrication parameters rather than changes in bulk chem-

istry. Three representative grayscale conditions (255, 200, and 150) were evaluated to

determine how grayscale exposure influenced hydrogel dimensional stability and glucose

transport.

### 4.3.1 Hydrogel Dimensional Equilibration in Media

Prior to di!usion testing, hydrogels were conditioned in culture media to assess dimen-

sional stability under hydrated operating conditions. Thickness and mass were measured

over time as the materials equilibrated. Across all conditions, hydrogels exhibited time-

dependent changes in geometry during the initial exposure period, followed by stabilization

at later time points. Representative thickness trends are shown in Figure 4.7.

Final equilibrated thicknesses di!ered systematically across grayscale conditions. The

highest grayscale condition (255) retained the greatest final thickness, while progressively

lower grayscale values resulted in thinner final structures. Mean final thicknesses are

31

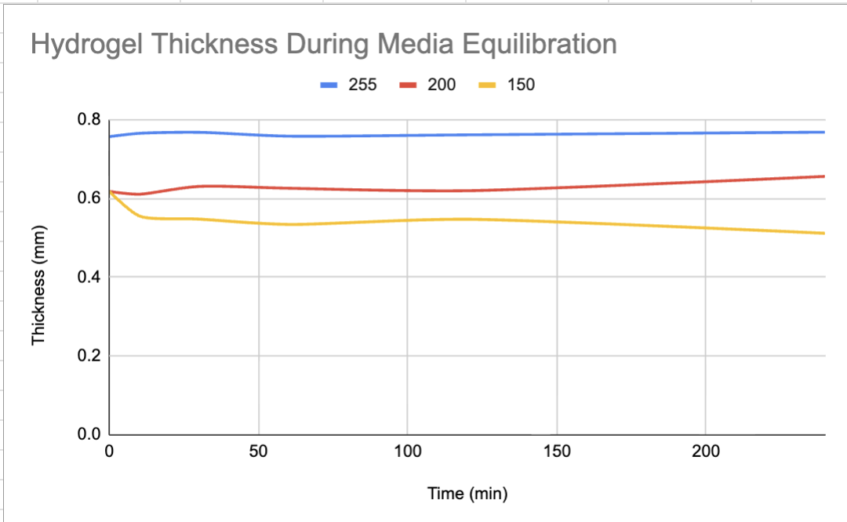
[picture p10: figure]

Figure 4.7: Mean hydrogel thickness over time during immersion in media for grayscale-defined constructs (255, 200, and 150), demonstrating condition-dependent dimensional stabilization.

Table 4.1: Final Mean Thicknesses of Grayscale Hydrogels

255 | 200 | 150
0.768 mm | 0.656 mm | 0.511 mm

shown in Table 4.1 and Figure 4.8.

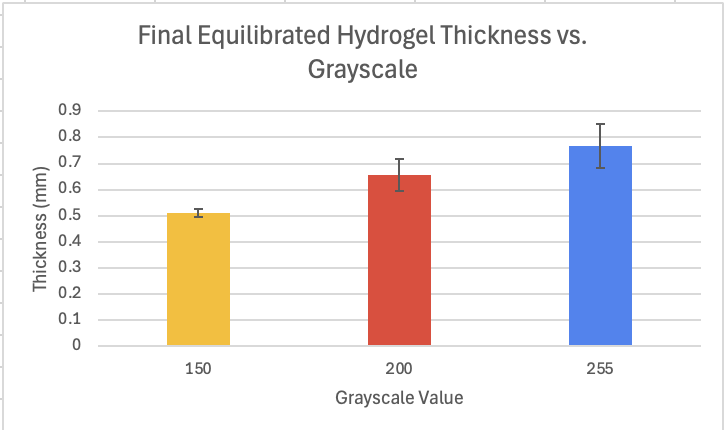
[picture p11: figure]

Figure 4.8: Mean final hydrated thickness after equilibration. Lower grayscale exposure produced thinner hydrogel barriers. Error bars represent standard deviation.

The observed decrease in final thickness with reduced grayscale exposure is consis-

tent with lower photopolymerization dose and reduced network crosslink density. Less

crosslinked hydrogels are expected to exhibit decreased structural rigidity and greater di-

mensional contraction or partial material loss during equilibration. In contrast, higher

grayscale constructs retained greater structural integrity in media.

Mass measurements exhibited greater variability than thickness data, likely due to

surface liquid retention and handling e!ects during weighing. As a result, thickness was

32

Table 4.2: Mean Receiver Concentrations at 10-hour t=Time Point

255 | 200 | 150
151 mg/dL | 181 mg/dL | 246 mg/dL

used as the primary geometric parameter for subsequent transport analysis.

### 4.3.2 Glucose Transport Across Grayscale-Defined Hydrogels

Glucose transport experiments were conducted by exposing one side of each hydrogel to

glucose-containing media and monitoring concentration increases in the receiver phase

over time. Mean glucose concentration profiles are shown in Figure 4.9.

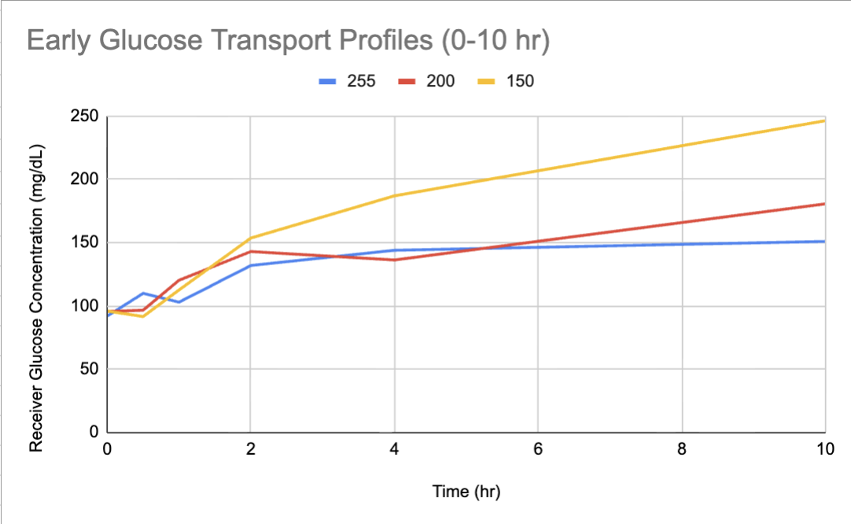
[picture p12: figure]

Figure 4.9: Early-time view of receiver glucose accumulation highlighting initial di!erences in transport kinetics between grayscale conditions.

All conditions demonstrated increasing receiver-phase glucose concentration over time,

confirming successful di!usion through the hydrogel barrier. However, transport behav-

ior varied substantially with grayscale condition. Lower-grayscale hydrogels exhibited

faster increases in concentration and higher intermediate-time glucose levels than higher-

grayscale samples.

At the 10-hour time point, mean receiver concentrations are shown in Table 4.2.

By 48 hours, the rank-order trend remained preserved, with the lowest grayscale con-

dition exhibiting the greatest total glucose transport.

These results indicate that decreasing grayscale value increases e!ective permeability

of the hydrogel barrier. This behavior is consistent with reduced crosslink density and

33

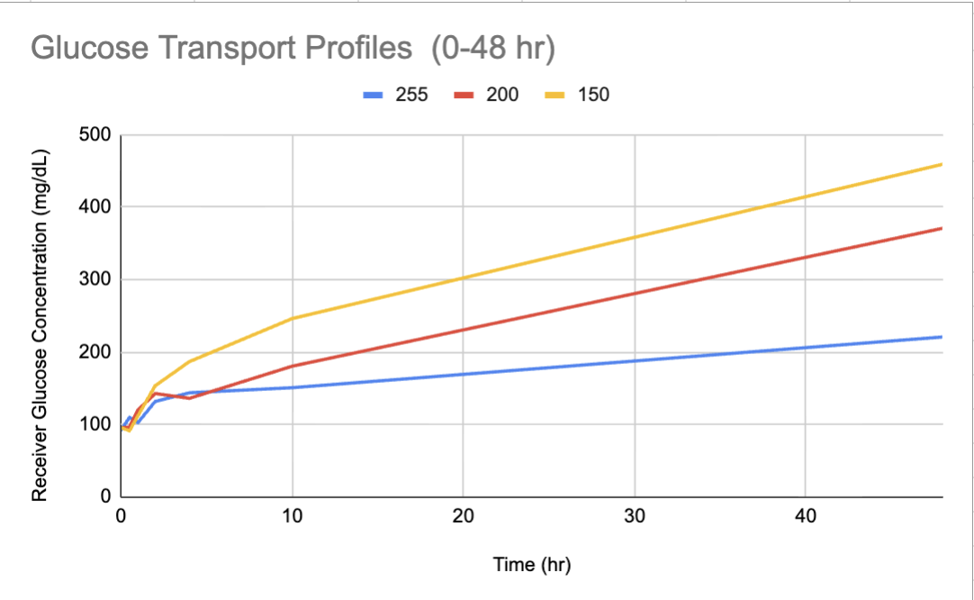
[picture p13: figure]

Figure 4.10: Mean receiver-phase glucose concentration over time following donor exposure. Lower grayscale hydrogels exhibited faster and greater glucose transport.

Table 4.3: E!ective Di!usivity of Grayscale Hydrogels Normalized to 255

255 | 200 | 150
1.0 | 1.23 | 1.70

larger e!ective mesh size, which would permit more rapid solute di!usion through the

polymer network.

Although replicate variability increased at later time points, particularly at 48 hours,

consistent monotonic trends were observed across conditions. The persistence of these

rank-order di!erences supports the conclusion that grayscale exposure reliably modulates

hydrogel transport behavior.

### 4.3.3 Thickness-Corrected E!ective Transport Behavior

Because lower grayscale hydrogels also exhibited reduced final thickness, part of the ob-

served transport increase could arise from a shorter di!usion path length rather than

changes in intrinsic permeability alone. To separate these e!ects, transport data were

corrected using measured final hydrogel thicknesses.

A relative transport index proportional to e!ective di!usivity was estimated using the

10-hour concentration rise and final hydrogel thickness. Results are shown in Figure 4.10.

When normalized to the 255 condition:

Thus, even after accounting for barrier thickness, lower grayscale hydrogels retained

substantially greater e!ective transport.

34

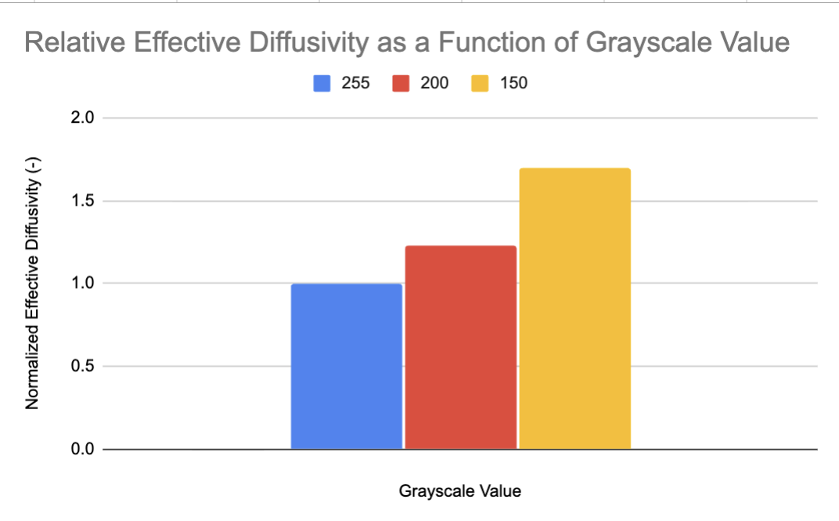
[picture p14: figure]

Figure 4.11: Normalized transport index proportional to e!ective di!usivity after correction for final hydrogel thickness. Lower grayscale conditions retained greater apparent intrinsic transport.

This finding indicates that grayscale exposure alters hydrogel transport through two

coupled mechanisms:

Geometric e!ects: thinner barriers reduce di!usion distance Material e!ects: lower

crosslinking density increases intrinsic permeability

Accordingly, grayscale-controlled photopolymerization provides a practical means of

tuning hydrogel transport properties without altering device geometry or polymer formu-

lation.

### 4.3.4 Implications for Capillary Barrier Mimicry

The ability to modulate glucose transport through grayscale exposure is directly relevant

to the objective of replicating physiological transport barriers such as capillary basement

membranes. In vivo, nutrient delivery is regulated not only by flow conditions but also by

selective structural barriers that delay and attenuate solute transport.

The present results demonstrate that hydrogel barriers can be tuned across a range of

transport behaviors through fabrication control alone. This enables selection of grayscale

conditions that approximate desired physiological permeability ranges or generate inten-

tionally altered transport states for disease modeling.

As a result, grayscale-defined hydrogels provide a flexible platform for constructing

transport-controlled microenvironments within microfluidic systems.

35

# Chapter 5

# Analysis and Discussion

## 5.1 Transport-Limited Microenvironments vs Conventional

## Models

Traditional in vitro systems typically assume that cells are exposed to spatially uniform

and temporally instantaneous concentrations of nutrients and signaling molecules. While

this simplifies experimental design, it neglects the role of transport processes that govern

solute delivery in vivo. In physiological environments, molecules such as glucose are deliv-

ered through vascular networks and must di!use across capillary barriers and interstitial

space before reaching target cells. This introduces spatial gradients and temporal delays

that are not captured in conventional culture systems. The microfluidic platform devel-

oped in this work addresses this limitation by introducing a transport barrier between the

flow channel and the cell chamber. By confining convective flow to a vascular channel and

requiring solutes to di!use through a hydrogel barrier, the system separates delivery from

exposure. As a result, cellular environments are shaped by transport dynamics rather

than imposed concentrations alone. This distinction is particularly relevant in the context

of metabolic diseases such as diabetes, where fluctuations in glucose concentration oc-

cur within a transport-mediated environment. The present system provides a framework

for studying how such dynamics influence cellular response under more physiologically

36

relevant conditions.

## 5.2 Decoupling of Flow and Di!usion

A key design feature of the platform is the decoupling of convective and di!usive trans-

port. Flow within the vascular channel is driven by hydrostatic pressure, producing steady,

laminar conditions that establish a controlled boundary concentration at the hydrogel in-

terface. Because the hydrogel prevents direct fluid flow into the cell chamber, solute

transport downstream is governed exclusively by di!usion. This separation enables inde-

pendent control of two critical variables: flow conditions, which determine the upstream

concentration profile, and hydrogel transport properties, which regulate solute propaga-

tion into the cell region. By isolating these mechanisms, the system minimizes confounding

e!ects that can arise in microfluidic systems where flow directly influences cellular expo-

sure. This design allows observed di!erences in downstream conditions to be attributed

to material and transport properties rather than hydrodynamic variability.

## 5.3 Hydrogel as a Tunable Transport Interface

The hydrogel barrier functions as the primary regulator of transport within the system.

Unlike traditional membranes with fixed properties, the hydrogel can be engineered to

exhibit tunable di!usivity through control of crosslinking density. In this work, grayscale-

controlled photopolymerization is used to define discrete hydrogel conditions correspond-

ing to di!erent levels of crosslinking. Variation in crosslinking density alters the e!ective

mesh size of the polymer network, which in turn a!ects solute di!usivity. As a result, the

hydrogel enables controlled modulation of permeability without altering device geometry.

This approach allows transport to be treated as an experimental variable rather than a

fixed parameter. Additionally, the use of spatially defined grayscale exposure introduces

the potential for structured heterogeneity within the hydrogel. While the present study

focuses on discrete conditions, this methodology can be extended to generate spatially

37

varying transport properties that more closely resemble discontinuous biological interfaces

such as sinusoidal capillaries.

## 5.4 Hydrogel Swelling and Equilibration Behavior

Prior to di!usion experiments, hydrogels were equilibrated in media to ensure stable ge-

ometry and hydration state. Measurements of thickness and mass over time indicate an

initial transient period followed by stabilization, consistent with swelling-driven equili-

bration. Thickness measurements were more consistent than mass measurements, which

exhibited variability likely associated with surface liquid retention and handling e!ects. As

a result, thickness was used as the primary parameter for defining the e!ective transport

distance in subsequent analysis. The observed stabilization of thickness over time sug-

gests that hydrogels reach approximate equilibrium within a finite timescale, after which

changes are within measurement variability. Establishing this equilibrium state is critical,

as di!usion behavior depends strongly on the barrier’s characteristic length scale.

## 5.5 Implications for Transport and Cellular Exposure

By introducing a tunable di!usion barrier, the system creates a microenvironment in

which cellular exposure is governed by both time and position. Rather than experiencing

a uniform concentration, cells are subjected to gradients that evolve as solutes di!use

through the hydrogel. This has important implications for experimental design and in-

terpretation. In transport-limited systems, increasing the concentration of a solute in the

upstream channel does not immediately translate to increased exposure at the cellular

level. Instead, exposure depends on the interplay between delivery and di!usion, which

may result in delayed or attenuated responses. Such e!ects are particularly relevant for

evaluating engineered biological systems, including stem cell spheroids and biomaterial-

based therapies, where local microenvironmental conditions play a critical role in function

and viability. The present platform provides a means to systematically investigate these

38

e!ects under controlled transport conditions.

## 5.6 Experimental Limitations

Several limitations of the current system should be noted. First, hydrostatic pressure-

driven flow, while simple and robust, may exhibit slight temporal variation as reservoir

levels change. However, these e!ects are minimized through the use of su”ciently large

reservoir volumes and consistent setup conditions. Second, while the hydrogel is treated

as locally isotropic, spatial variations in crosslinking introduce heterogeneity that is not

fully captured in simplified transport models. More detailed characterization of spatially

varying di!usivity would improve predictive accuracy. Third, the current study isolates

di!usion-driven transport and does not account for cellular consumption of solutes. In

biological systems, uptake and metabolism introduce additional gradients that couple

transport with reaction kinetics. Incorporating such e!ects represents an important di-

rection for future work. Finally, while preliminary imaging demonstrates compatibility of

the hydrogel environment with cells, comprehensive biological validation within the full

transport-controlled system remains to be completed.

39

# Chapter 6

# Conclusion and Future Work

## 6.1 Summary of Work and Key Findings

This work presented the design and development of a microfluidic platform to study

transport-limited solute delivery in a physiologically inspired environment. The system

was constructed to decouple convective transport within a vascular channel from di!u-

sive transport across a hydrogel barrier, enabling controlled investigation of how solutes

propagate from a flowing medium into a downstream region. Hydrodynamic character-

ization confirmed that the flow within the vascular channel is laminar and stable, with

predictable velocity profiles and pressure gradients. Hydrostatic pressure-driven flow was

shown to provide a simple and e!ective method to maintain perfusion without the need

for external pumping systems. Experimental validation demonstrated an average hydro-

static flow rate of approximately 10 µL/min, corresponding to a mean channel velocity

of 0.40 mm/s under standard operating conditions. Hydrogel characterization estab-

lished the importance of equilibration prior to transport experiments. Thickness measure-

ments indicated that hydrogels reached an approximately stable hydrated state within the

first 1–2 hours, after which subsequent changes were comparatively small and remained

within normal measurement variability. Final equilibrated thickness depended strongly

on grayscale exposure condition. Mean hydrated thicknesses were 0.768 mm (255), 0.656

mm (200), and 0.511 mm (150). These values were used as the characteristic di!usion

40

path lengths for subsequent transport analysis. Di!usion studies across hydrogels of vary-

ing grayscale-defined crosslinking density revealed clear di!erences in transport behavior.

Receiver-phase glucose concentration increased over time for all conditions, confirming

successful solute transport across the barrier. At 10 hours, mean receiver concentrations

were 151 mg/dL (255), 181 mg/dL (200), and 246 mg/dL (150). By 48 hours, concen-

trations further increased to approximately 220 mg/dL (255), 370 mg/dL (200), and 460

mg/dL (150), indicating progressively greater cumulative transport at lower grayscale

values. These results demonstrate that higher grayscale exposure corresponded to lower

e!ective permeability, while reduced grayscale exposure increased solute transport. After

correcting for thickness di!erences, the normalized relative e!ective di!usivity values were

1.00 (255), 1.23 (200), and 1.70 (150). This indicates that transport di!erences were not

caused solely by barrier thickness, but also by grayscale-dependent changes in intrinsic

hydrogel permeability. Collectively, these findings demonstrate that grayscale-controlled

photopolymerization provides an e!ective method for tuning transport properties within

microfluidic systems. Collectively, these findings demonstrate that the platform is capable

of generating controlled, transport-limited microenvironments in which solute delivery is

governed by both flow and di!usion. Looking at the objectives laid out by this project,

most have been met. First, this project set out to fabricate a leak-resistant chip, which

was completed by testing the chip qualitatively for leaks during perfusion. Next, passive

perfusion was validated to produce stable and consistent flow by flow validation. Hy-

drogels were shown to have tunable transport properties by altering grayscale values and

measuring e!ective di!usion. Finally, the goal of producing a platform suitable for future

cell-based studies was partially met. The platform requires future di!usion testing with

a cell monolayer and tissue cell experiments, which were outside the scope of the present

work.

41

## 6.2 Significance of Transport-Controlled Microenvironments

A central contribution of this work is the explicit incorporation of a transport barrier into

a microfluidic system. In contrast to conventional in vitro models, which assume uniform

exposure, the present platform enforces a separation between solute delivery and cellular

exposure. This results in concentration profiles that evolve over time and space, more

closely reflecting physiological conditions. In vivo, solutes such as glucose are delivered

through vascular networks and must traverse both endothelial layers and underlying base-

ment membranes before reaching target cells. These processes introduce delays, gradients,

and attenuation that are not captured in traditional culture systems. By modeling the

basement membrane as a tunable hydrogel barrier, this work provides a first step toward

incorporating these transport phenomena into in vitro platforms. The ability to control

transport independently of flow enables systematic investigation of how microenvironmen-

tal conditions influence cellular behavior. This is particularly important in the context of

metabolic diseases, where fluctuations in solute concentration occur within a transport-

mediated framework. The present system, therefore, o!ers a more physiologically relevant

approach to studying disease mechanisms and therapeutic response.

## 6.3 Future Work

### 6.3.1 Di!usion Characterization with Endothelial Layers

While the current system models di!usion across a capillary-like basement membrane us-

ing a hydrogel barrier, it does not yet incorporate the endothelial layer that forms the

primary interface between blood flow and tissue. In vivo, solute transport across capillar-

ies occurs through multiple pathways, including di!usion across endothelial cells, trans-

port through tight junctions, and transendothelial channels. Future work will extend the

platform by incorporating an endothelial monolayer at the interface between the vascular

channel and the hydrogel. This addition will enable investigation of how cellular barriers

modulate transport in conjunction with the underlying hydrogel. In particular, the com-

42

bined e!ects of endothelial permeability and hydrogel di!usivity can be studied to better

approximate physiological transport across sinusoidal capillaries. Quantitative compari-

son between hydrogel-only and endothelial-integrated systems will provide insight into the

relative contributions of basement membrane and cellular transport pathways. This rep-

resents a critical step toward developing a more complete and biologically representative

capillary model.

### 6.3.2 Influence of Residence Time on Transport Behavior

The present system introduces a serpentine vascular channel designed to increase residence

time and enhance interaction between the flowing medium and the di!usion interface.

However, the relationship between residence time and downstream concentration profiles

has not yet been fully characterized. Future studies will investigate how variations in flow

rate and channel geometry a!ect residence time and, consequently, solute delivery to the

hydrogel interface. By systematically varying hydrostatic pressure and channel length, it

will be possible to determine how upstream transport conditions influence di!usion-driven

exposure. Understanding this relationship is important for distinguishing between systems

in which transport is limited by di!usion through the barrier and those in which upstream

delivery plays a dominant role. This analysis will further clarify the interplay between

convection and di!usion in shaping microenvironmental conditions.

### 6.3.3 Role of Transient Concentration Spikes vs Di!usion-Limited Ex-

posure

In conventional in vitro experiments, cells are often exposed to rapid changes in solute con-

centration, resulting in transient spikes that may not accurately reflect in vivo conditions.

In contrast, transport-limited systems introduce delays and gradients that may attenuate

or redistribute these changes. Future work will examine whether cellular responses are

driven primarily by peak concentration exposure or by the time-dependent di!usion pro-

file. By comparing systems with direct exposure to those with di!usion-mediated delivery,

43

it will be possible to assess the relative importance of transient spikes versus sustained

gradients. This distinction is particularly relevant for studying metabolic signaling and

therapeutic delivery, where the timing and magnitude of exposure may significantly influ-

ence cellular outcomes.

### 6.3.4 Evaluation of Stem Cell Spheroids in Transport-Controlled Envi-

ronments

The next phase of this work will involve integration of stem cell spheroids into the mi-

crofluidic platform to evaluate their behavior under transport-limited conditions. These

spheroids, which are designed to retain stemness and support tissue regeneration through

secretome modulation, represent a promising therapeutic approach for conditions such

as diabetic cartilage degeneration. By placing spheroids within the di!usion-controlled

chamber, the platform can be used to assess how transport dynamics influence cellular

viability, signaling, and therapeutic e”cacy. In particular, the system enables investiga-

tion of how limited nutrient delivery and gradient formation a!ect spheroid function. This

application represents a shift from validating the platform itself to using it as a tool for

evaluating emerging therapies under physiologically relevant conditions.

## 6.4 Final Conclusions

This work demonstrates the feasibility of engineering a microfluidic system in which so-

lute transport is explicitly controlled through the integration of convective flow and dif-

fusive barriers. By combining hydrostatic flow, tunable hydrogel interfaces, and spatially

defined transport conditions, the platform establishes a framework for studying how mi-

croenvironmental dynamics influence biological systems. A key insight of this work is that

transport barriers play a fundamental role in shaping cellular exposure. In physiological

systems, cells do not experience uniform concentrations, but rather gradients governed by

the interplay of flow, di!usion, and structural interfaces. Incorporating these e!ects into

in vitro models is essential for improving their relevance and predictive capability. The

44

platform developed here provides a step toward this goal by enabling controlled, tunable

transport conditions that more closely resemble those found in vivo. While further work

is required to incorporate additional biological complexity, including endothelial layers

and cellular consumption, the system establishes a foundation for future studies in drug

testing, tissue engineering, and disease modeling. Ultimately, the integration of transport

phenomena into microfluidic systems represents a critical advancement in the development

of physiologically realistic models. By shifting the focus from static exposure to dynamic,

transport-mediated environments, this work contributes to a more accurate understanding

of how biological systems respond to their surroundings.

45

## Appendix A: Computational Modeling Methods and Repos-

## itory

Full CFD simulation files, geometry files, and supporting analysis materials associated

with this thesis are available in the public project repository:

https://github.com/jlevin8/microfluidicchipcapstone2026

Repository contents include simulation geometries, boundary condition definitions,

mesh files, and exported post-processing results su”cient to reproduce the computational

analyses presented in Chapter 4.

46

# Bibliography

Hofbauer, Lorenz C. et al. (2022). “Bone fragility in diabetes: Novel concepts and clinical

implications”. In: The Lancet Diabetes & Endocrinology 10.3, pp. 207–220. doi: 10.

1016/S2213-8587(21)00347-8.

Napoli, Nicola et al. (2017). “Mechanisms of diabetes mellitus-induced bone fragility”. In:

Nature Reviews Endocrinology 13.4, pp. 208–219. doi: 10.1038/nrendo.2016.153.

Vestergaard, Peter (2007). “Discrepancies in bone mineral density and fracture risk in pa-

tients with type 1 and type 2 diabetes–a meta-analysis”. In: Osteoporosis International

18.4, pp. 427–444. doi: 10.1007/s00198-006-0253-4.

Schwartz, Ann V. (2016). “Epidemiology of fractures in type 2 diabetes”. In: Bone 82,

pp. 2–8. doi: 10.1016/j.bone.2015.05.032.

Janghorbani, Mohsen et al. (2007). “Systematic review of type 1 and type 2 diabetes

mellitus and risk of fracture”. In: American Journal of Epidemiology 166.5, pp. 495–

505. doi: 10.1093/aje/kwm106.

Karner, Christopher M. and Fanxin Long (2017). “Wnt signaling and cellular metabolism

in osteoblasts”. In: Cellular and Molecular Life Sciences 74.9, pp. 1649–1657. doi:

10.1007/s00018-016-2425-5.

Yamamoto, Masahiro and Toshitsugu Sugimoto (2016). “Advanced Glycation End Prod-

ucts, Diabetes, and Bone Strength”. In: Current Osteoporosis Reports 14.6, pp. 320–

326. doi: 10.1007/s11914-016-0332-1.

Jain, Rakesh K. (1987). “Transport of molecules in the tumor interstitium: A review”. In:

Cancer Research 47.12, pp. 3039–3051.

47

Michel, C. C. and F. E. Curry (1999). “Microvascular permeability”. In: Physiological

Reviews 79.3, pp. 703–761. doi: 10.1152/physrev.1999.79.3.703.

Prisby, Rhonda D. (2017). “Mechanical, hormonal and metabolic influences on blood

vessels, blood flow and bone”. In: Journal of Endocrinology 235.3, R77–R100. doi:

10.1530/JOE-16-0666.

Zhang, Yang et al. (2023). “Bone-on-a-chip platforms and integrated biosensors: Towards

advanced in vitro bone models with real-time biosensing”. In: Biosensors and Bioelec-

tronics 219, p. 114798. doi: 10.1016/j.bios.2022.114798.

Zhang, B. et al. (2018). “Advances in organ-on-a-chip engineering”. In: Nature Reviews

Materials 3, pp. 257–278. doi: 10.1038/s41578-018-0034-7.

Van Norman, Gail A. (2019). “Limitations of animal studies for predicting toxicity in

clinical trials”. In: JACC: Basic to Translational Science 4.7, pp. 845–854. doi: 10.

1016/j.jacbts.2019.10.008.

Seok, Jinhee, H. Shaw Warren, Alex G. Cuenca, et al. (2013). “Genomic responses in mouse

models poorly mimic human inflammatory diseases”. In: Proceedings of the National

Academy of Sciences 110.9, pp. 3507–3512. doi: 10.1073/pnas.1222878110.

Edmondson, Rasheeda et al. (2014). “Three-dimensional cell culture systems and their

applications in drug discovery and cell-based biosensors”. In: Assay and Drug Devel-

opment Technologies 12.4, pp. 207–218. doi: 10.1089/adt.2014.573.

Yurchenco, Peter D. (2011). “Basement membranes: Cell sca!oldings and signaling plat-

forms”. In: Cold Spring Harbor Perspectives in Biology 3.2, a004911. doi: 10.1101/

cshperspect.a004911.

Williamson, Jerry R., Charles Kilo, and Robert G. Tilton (1993). “Mechanisms of diabetic

microangiopathy”. In: Diabetes 42.6, pp. 801–813. doi: 10.2337/diab.42.6.801.

Bird, R. Byron, Warren E. Stewart, and Edwin N. Lightfoot (2002). Transport Phenomena.

2nd ed. John Wiley & Sons.

Brownlee, Michael (2001). “Biochemistry and molecular cell biology of diabetic complica-

tions”. In: Nature 414.6865, pp. 813–820. doi: 10.1038/414813a.

48

Peppas, Nicholas A. et al. (2000). “Hydrogels in pharmaceutical formulations”. In: Euro-

pean Journal of Pharmaceutics and Biopharmaceutics 50.1, pp. 27–46. doi: 10.1016/

S0939-6411(00)00090-4.

Zhu, Jun and Robert E. Marchant (2011). “Design properties of hydrogel tissue-engineering

sca!olds”. In: Expert Review of Medical Devices 8.5, pp. 607–626. doi: 10.1586/erd.

11.27.

Yue, Kun et al. (2015). “Synthesis, properties, and biomedical applications of gelatin

methacryloyl (GelMA) hydrogels”. In: Biomaterials 73, pp. 254–271. doi: 10.1016/

j.biomaterials.2015.08.045.

Amsden, Brian (1998). “Solute di!usion within hydrogels”. In: Macromolecules 31.23,

pp. 8382–8395. doi: 10.1021/ma980765f.

Whitesides, George M. (2006). “The origins and the future of microfluidics”. In: Nature

442.7101, pp. 368–373. doi: 10.1038/nature05058.

Waheed, Saqib et al. (2016). “3D printed microfluidic devices: Enablers and barriers”. In:

Lab on a Chip 16.11, pp. 1993–2013. doi: 10.1039/C6LC00284F.

Huh, Dongeun et al. (2010). “Reconstituting organ-level lung functions on a chip”. In:

Science 328.5986, pp. 1662–1668. doi: 10.1126/science.1188302.

Bhatia, Sangeeta N. and Donald E. Ingber (2014). “Microfluidic organs-on-chips”. In:

Nature Biotechnology 32.8, pp. 760–772. doi: 10.1038/nbt.2989.

Hudetz, A. G. (1997). “Blood flow in the cerebral capillary network: a review emphasizing

observations with intravital microscopy.” In: Microcirculation 4.2, pp. 233–252. doi:

10.3109/10739689709146787.

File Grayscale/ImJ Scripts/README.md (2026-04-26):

# ImageJ Scripts

## xxx_gradient.js

This script is for **ImageJ**. It fills a white region in your image with a grayscale value.  
It only changes the white part (your object), leaving the background untouched.

---

## 1. What you need
- **ImageJ** (download from https://imagej.net/ij/)  
- The script file: `xxx_gradient.js` (xxx is 150,200,250, or a value of your choosing.)

---

## 2. Running the script

1. Open ImageJ.  
2. Open your image (**File → Open...**).  
3. Go to **Plugins → Macros → Run...**  
4. Choose `xxx_gradient.js`.  
5. The gradient will be applied instantly.

---

## 3. How it works
- It looks for **white pixels** in your image.  
- Fills those pixels with a **flat value**.  
- Leaves all non-white pixels unchanged.  
- Optional settings can add a small “notch” or a bit of noise for texture.

---

## 4. Adjusting the settings
At the top of the script you’ll see lines like:

```javascript
// Gradient
var GRAY_MIN = 150;          // left edge gray
var GRAY_MAX = 150;          // right edge gray
```
---

## 5. This can also be used to create a left to right gradient by changing the MIN and MAX variables to different values.

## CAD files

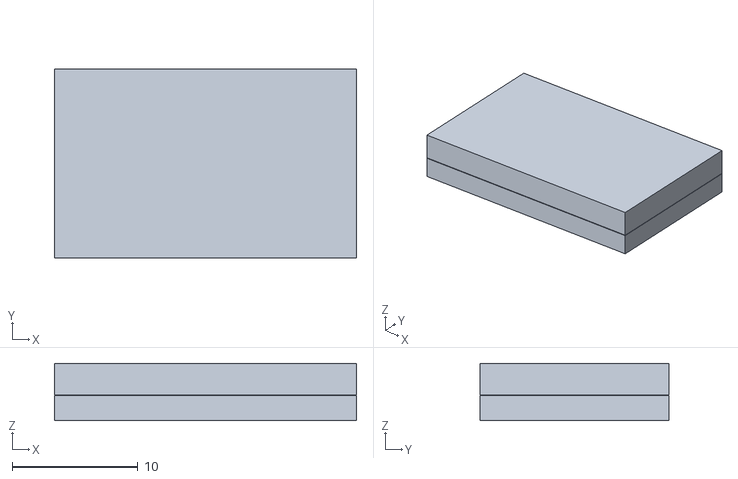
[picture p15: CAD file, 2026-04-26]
CAD/Chip Assembly.stl
24.0 x 15.0 x 4.55

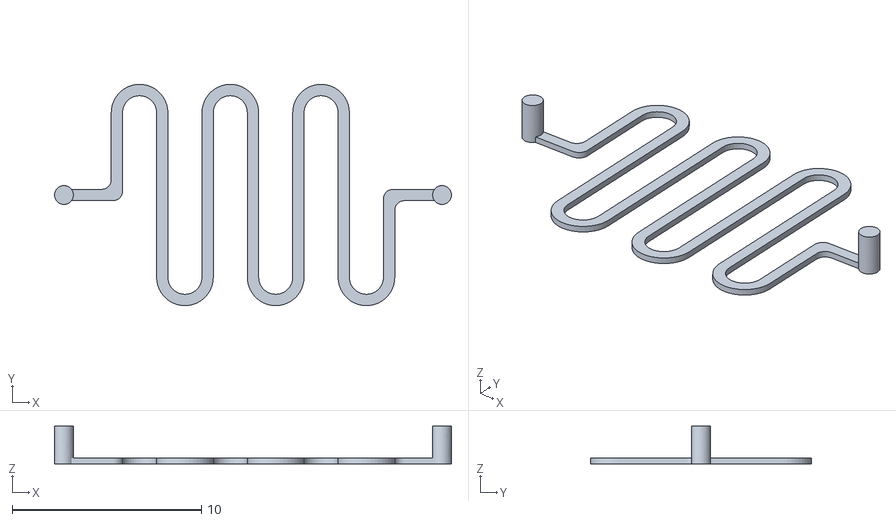
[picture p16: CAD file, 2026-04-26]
bonechipCFD/constant/triSurface/channelFlow.stl
21.0 x 11.7 x 2.00

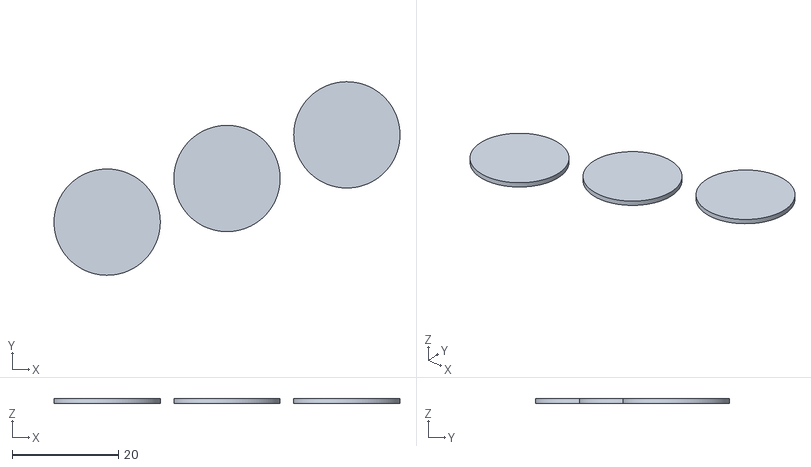
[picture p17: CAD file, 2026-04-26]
Grayscale/3X 20x1mm Cylinders.stl
65.1 x 36.4 x 1.00

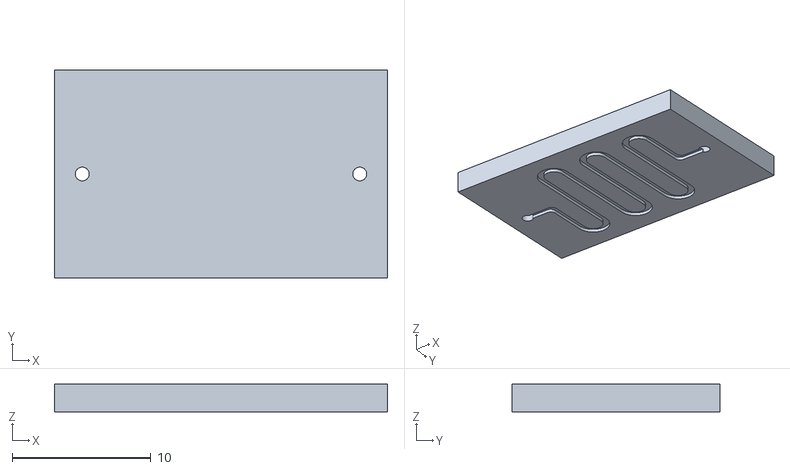
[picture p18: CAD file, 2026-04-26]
CAD/Chip Positive Top.stl
24.0 x 15.0 x 2.00

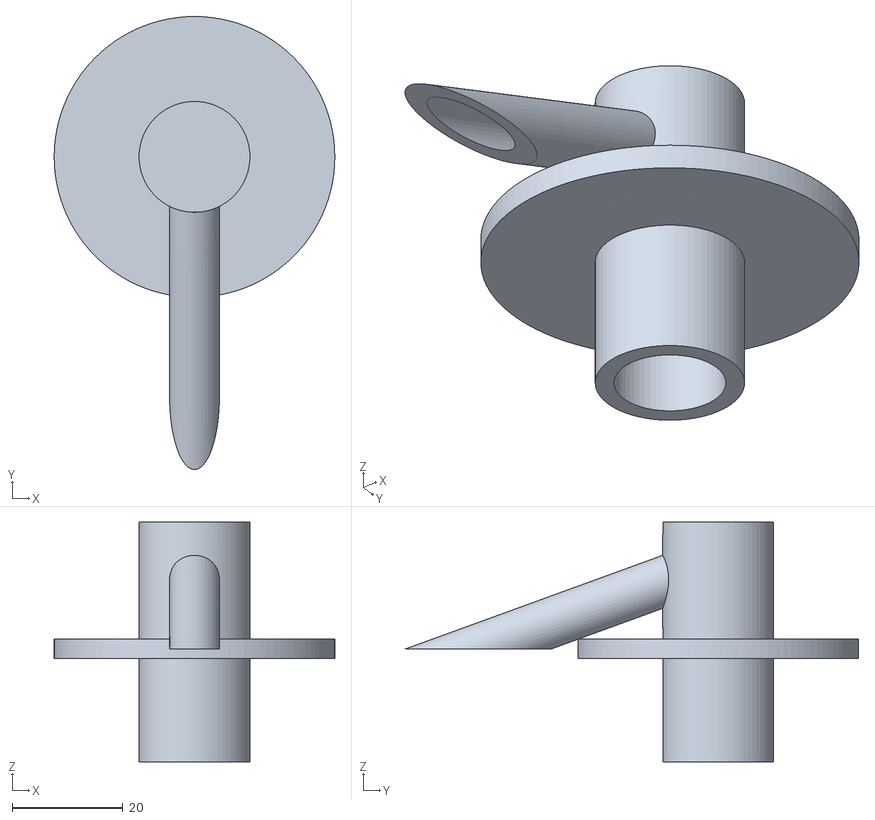
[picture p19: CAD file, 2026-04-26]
CAD/Modified Franz Cell.stl
50.6 x 81.7 x 43.2

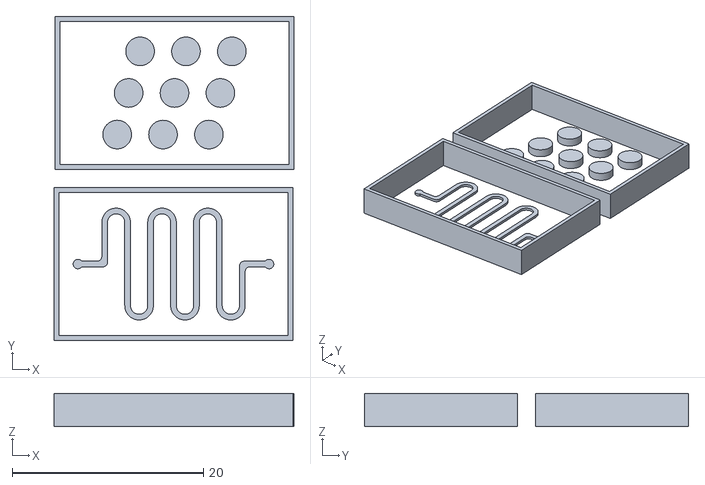
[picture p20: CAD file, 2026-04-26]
CAD/Chip Negative Molds Bottom and Top.stl
25.1 x 33.9 x 3.50

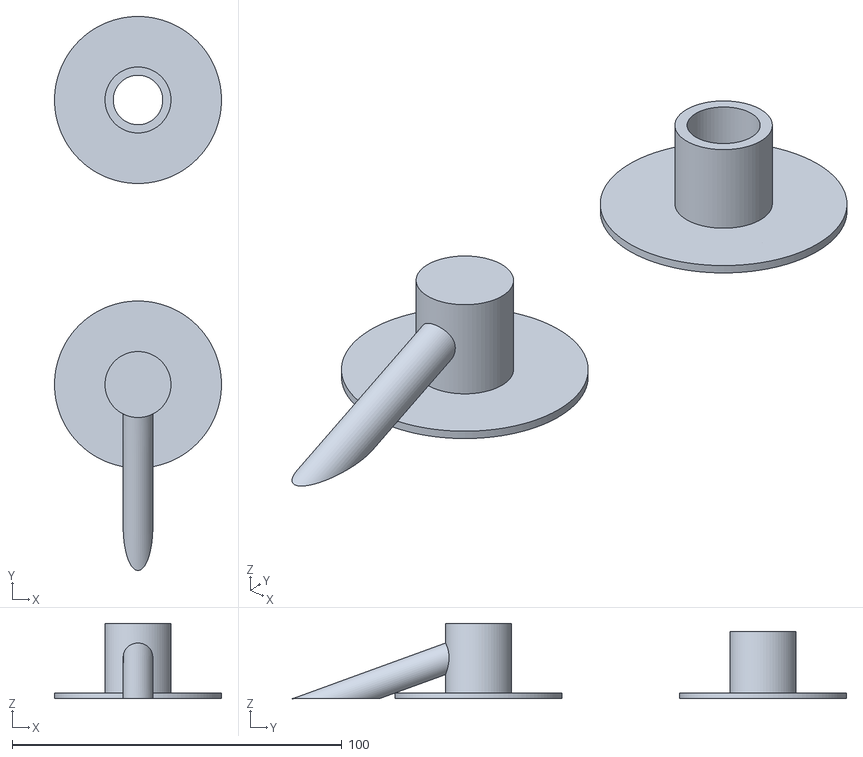
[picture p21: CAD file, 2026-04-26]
CAD/Diffusion Cell Separated.stl
50.6 x 168.0 x 22.9

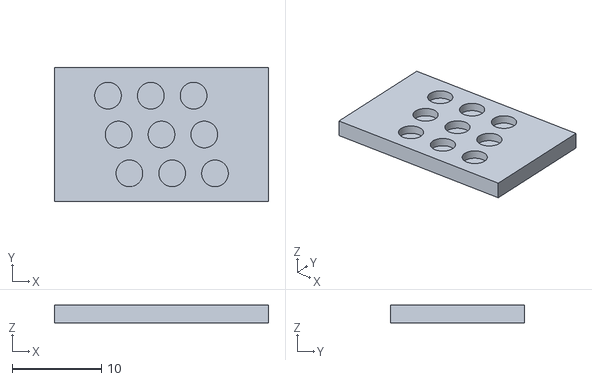
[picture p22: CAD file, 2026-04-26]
CAD/Bottom Layer Chip Positive.stl
24.0 x 15.0 x 2.00

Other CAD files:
bonechipCFD/constant/extendedFeatureEdgeMesh/channelFlow_mixedFeaturePts.obj
CAD/Chip Flow.stl
bonechipCFD/constant/extendedFeatureEdgeMesh/channelFlow_edgeDirections.obj
bonechipCFD/constant/triSurface/clean_channel.stl
bonechipCFD/constant/extendedFeatureEdgeMesh/channelFlow_internalEdges.obj
bonechipCFD/constant/extendedFeatureEdgeMesh/channelFlow_externalEdges.obj
bonechipCFD/constant/extendedFeatureEdgeMesh/channelFlow_edgeMesh.obj
bonechipCFD/constant/extendedFeatureEdgeMesh/channelFlow_mixedFeaturePtsStructure.obj

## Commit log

2026-04-26 3D Files from Fusion
    .stl files used for 3D Prints including chip negative molds, positive slabs, diffusion cell, flow path used for CFD, and assembled chip.
    [Bottom Layer Chip Positive.stl, Chip Assembly.stl, Chip Flow.stl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]
2026-04-26 CFD Files
    [channelFlow.stl, channelFlow_edgeDirections.obj, channelFlow_edgeMesh.obj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]
2026-04-26 Create CAD Folder
2026-04-26 deleted extra cad
